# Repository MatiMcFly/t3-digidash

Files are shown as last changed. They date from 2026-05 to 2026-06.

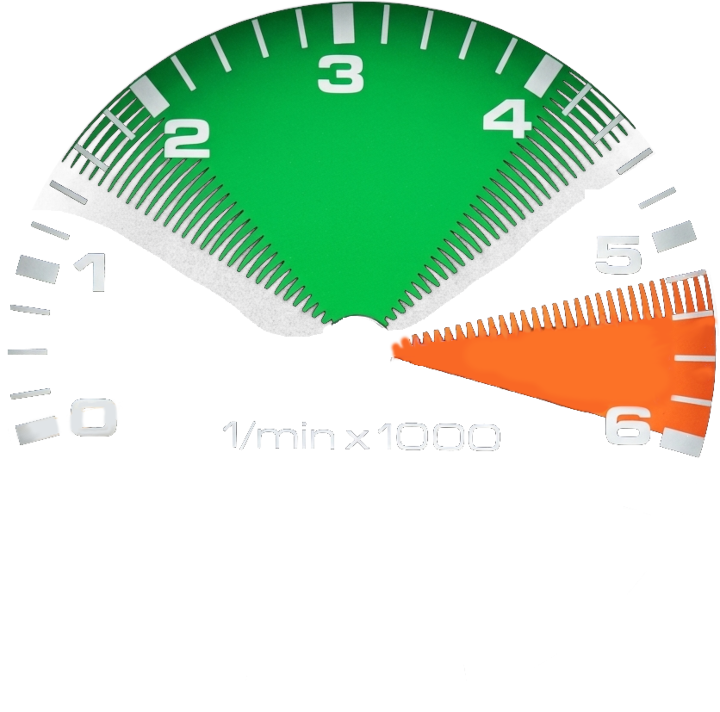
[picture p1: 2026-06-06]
fw/disco/CM7/TouchGFX/assets/images/t3-rpm-scale.png

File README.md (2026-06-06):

# 🛻 T3 DigiDash -- Digital dashboard for the VW T3

(C) 2026 Matthias Schär, Rinaldo Leone, Timon Burkard

This is a project work part of the CAS Embedded Systems at FHNW Brugg-Windisch.

## Docs

Documentation, specification etc. can be found in [docs](docs/) directory.

## FW

This project consists of three firmware projects:

- [Disco](fw/disco/) -- ST Discovery Kit: STM32H747I-DISCO
- [Nucleo](fw/nucleo/) -- ST Nucleo Board: NUCLEO-H755ZI-Q
- [ESP](fw/esp/) -- Seeed ESP Board: ESP-C3

## HW

This project consists of four hardware projects:

- [disco-tft-adapter](hw/disco-tft-adapter/) -- Discovery Board TFT Adapter
- [t3-harness-adapter](hw/t3-harness-adapter/) -- T3 Wiring harness adapter
- [measurement-circuits](hw/measurement-circuits/) -- Collects all of the measurement circuits used
- [signal-emulator](hw/signal-emulator/) -- Sensor signal emulator (used for testing and demonstration)

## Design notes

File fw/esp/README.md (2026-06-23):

# ESP32-C3 UART, BLE, and RemoteXY Bridge

This firmware receives ASCII telemetry over UART, parses it into car-signal values, and exposes those values over BLE.
It also embeds a RemoteXY-compatible BLE interface so a dashboard app can connect and read the same live data.

## What It Does
- Reads UART telemetry on GPIO4/GPIO5 at 115200 8N1
- Parses semicolon-separated `id:value` pairs into internal car-signal state
- Updates BLE characteristics for water temperature, RPM, battery voltage, tank level, turn signal, high beam, and oil-pressure switches
- Advertises a custom car-signals service plus standard Environmental Sensing and Battery services
- Exposes an HM-10-style BLE UART service for RemoteXY traffic
- Reconnects and re-advertises automatically after disconnects

## Current Firmware Layout
- `main/app_main.c` starts BLE, RemoteXY, and the UART task
- `main/uart_task.c` reads and parses UART telemetry
- `main/uart_parser.c` decodes the `id:value` message format
- `main/car_signals.c` stores signal state and triggers BLE notifications
- `main/gatt_db.c` defines the BLE GATT services and characteristics
- `main/remotexy_protocol.c` handles the RemoteXY command exchange

## Requirements
- ESP-IDF 6.0.1
- ESP32-C3 target
- A BLE client app such as nRF Connect, or a RemoteXY-compatible mobile app
- An external UART source that emits the expected telemetry format

## Build and Flash
```bash
idf.py set-target esp32c3
idf.py build
idf.py -p <PORT> flash monitor
```

## Hardware Wiring
- ESP32-C3 GPIO4 (UART TX) -> RX of the external device
- ESP32-C3 GPIO5 (UART RX) -> TX of the external device
- GND -> GND
- RTS/CTS are not used

## UART Message Format
The parser expects a semicolon-separated stream of `id:value` pairs.

Example:
```text
1:23.5;2:1500;3:12.6;4:18.2;5:1;6:0;7:1;8:0;
```

Field mapping:
- `1` = water temperature
- `2` = RPM
- `3` = battery voltage
- `4` = tank level
- `5` = turn signal
- `6` = high beam
- `7` = oil pressure switch 0.3B
- `8` = oil pressure switch 1.8B

The parser is tolerant of streaming input and collects bytes until it finds `;` separators.

## BLE Services
The firmware advertises as `T3 DigiDash`.

Available services:
- Standard Environmental Sensing service `0x181A`
	- Temperature characteristic `0x2A6E`
- Standard Battery service `0x180F`
	- Battery Level characteristic `0x2A19`
- HM-10 compatible UART service `0xFFE0`
	- UART characteristic `0xFFE1` for RemoteXY command traffic
- Custom Car Signals service `c4e7b1a2-0f3d-4f2a-8d89-0d92b48e7d21`
	- RPM
	- Turn Signal
	- High Beam
	- Tank Level
	- Battery Voltage

Use nRF Connect to inspect the GATT table and enable notifications on the characteristics you want to watch.

## RemoteXY
RemoteXY support is built in and uses the BLE UART characteristic for control packets.
The firmware responds to configuration, ping, time, board, and variable update commands so a compatible dashboard can connect without extra glue code.

## UART Simulator
A small Python-based UART generator is available in `uart_py_simulator/` for local testing.
See that folder's README for setup and run commands.

## Notes
- BLE notifications are chunked for the UART/RemoteXY path
- Hardware flow control is disabled
- The project currently focuses on live telemetry bridging rather than local UI or storage

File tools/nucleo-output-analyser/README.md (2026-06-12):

# Motor RPM Tools

Two Python scripts for capturing and visualising motor RPM data from a serial device.

## Requirements

```bash
pip install -r requirements.txt
```

---

## `live_motor_rpm.py` — Live serial monitor

Connects to a serial port, parses incoming datasets and displays a continuously
scrolling RPM plot in real time.

```
usage: live_motor_rpm.py [--port PORT] [--baud BAUD] [--window SECONDS]

options:
  --port    Serial device to read from   (default: /dev/ttyACM0)
  --baud    Baud rate                    (default: 115200)
  --window  Visible time window (s)      (default: 60)
```

**Examples**

```bash
# Use defaults (/dev/ttyACM0, 115200 baud, 60 s window)
python3 live_motor_rpm.py

# USB adapter at 9600 baud, show last 2 minutes
python3 live_motor_rpm.py --port /dev/ttyUSB0 --baud 9600 --window 120
```

---

## `plot_motor_rpm.py` — Log file plotter

Parses a minicom log file and plots the recorded RPM values over time.
Prints basic statistics (min, max, mean RPM) to the terminal.

```
usage: plot_motor_rpm.py [logfile] [--interval SECONDS]

arguments:
  logfile     Path to the minicom log file  (default: data/minicom-output.log)

options:
  --interval  Sample interval in seconds    (default: 0.1)
```

**Examples**

```bash
# Use the default log file (data/minicom-output.log)
python3 plot_motor_rpm.py

# Specify a different log file
python3 plot_motor_rpm.py data/my_run.log

# Log recorded at 20 Hz (0.05 s per sample)
python3 plot_motor_rpm.py data/my_run.log --interval 0.05
```

---

## Expected serial / log format

Both tools expect datasets delimited by a `Turn Signal:` line, with an optional
`Motor RPM:` line inside each dataset:

```
Turn Signal: ...
Motor RPM:   1450 rpm
...
Turn Signal: ...
Motor RPM:   1480 rpm
...
```

Datasets missing a `Motor RPM:` line are recorded as **0 RPM**.

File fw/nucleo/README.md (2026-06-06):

# Nucleo Firmware

Firmware for the STM32H755XI microcontroller with ARM Cortex-M7 and Cortex-M4 core, which is on a NUCLEO-H755ZI-Q board.

M4 core handles all sensor data related operations and then sends processed sensor data to M7 via IPC (Inter-processor communication), which handles UART communication.

## Features

- **M4 Core**
  - Sensor data acquisition (ADC + DMA)
  - Data conversion
  - Data filtering
  - Debug message publication via UART3 (virtual serial COM port)
  - IPC transmission to M7 via FreeRTOS message buffer in shared SRAM4 and notification via HSEM1
  - Heartbeat LED (LD1)
- **M7 Core**
  - IPC reception from shared message buffer, notification via HSEM1
  - UART1 output of received sensor messages
  - Heartbeat LED (LD2)

## Pinout

| Function | Core | Peripheral | Pins |
| --- | ---- | --- | --- |
| Sensor 1: Coolant temperature  | M4 | ADC1_INP2  | PF11 |
| Sensor 2: Motor RPM | M4 | TIM2_CH1 | PA0 |
| Sensor 3: Battery voltage | M4 | ADC1_INP3  | PA6 |
| Sensor 4: Fuel level | M4 | ADC1_INP5  | PB1 |
| Sensor 5: Turn signal | M4 | GPIO | D0 |
| Sensor 6: High beam | M4 | GPIO | D1 |
| Sensor 7: Oil pressure 0.3 bar | M4 | GPIO | D2 |
| Sensor 8: Oil pressure 1.8 bar | M4 | GPIO | D3 |
| Debug UART | M4 | USART3 | PD8 (TX), PD9 (RX) |
| Output UART | M7 | USART1 | PB14 (TX), PB15 (RX) |
| Heartbeat LED | M4 | GPIO | PB0 (LD1) |
| Heartbeat LED | M7 | GPIO | PE1 (LD2) |

## UART

- Baud: 115'200
- Data: 8 bit
- Stop: 1 bit
- Parity: None

### Output UART

Formatted sensor data frames:

```
<id>:<value>
```

### Debug UART

No strict format; debugging purpose only.

## Flow Chart

### M4 Core

```mermaid
flowchart TB
    ACQ[Acquisition Task\n1 Hz trigger]
    ISR[HAL_ADC_ConvCpltCallback]
    CONV[Conversion Task]
    FILT[Filtering Task]
    PUB[Publication Task]
    HB[Heartbeat Task]

    QRAW[(queue_data_raw)]
    QCONV[(queue_data_converted)]
    QFILT[(queue_data_filtered)]
    IPC[(MessageBuffer in SRAM4)]
    HSEM[(HSEM1 notify)]

    ADC[(ADC1 + DMA1 Stream0)]
    UART[(Debug USART3)]
    LED[(LD1)]

    ACQ -->|HAL_ADC_Start_DMA| ADC
    ADC -->|DMA transfer complete IRQ| ISR

    ISR -->|xQueueSendFromISR| QRAW

    QRAW -->|xQueueReceive| CONV
    CONV -->|xQueueSend| QCONV

    QCONV -->|xQueueReceive| FILT
    FILT -->|xQueueSend| QFILT

    QFILT -->|xQueueReceive| PUB
    PUB -->|HAL_UART_Transmit| UART
    PUB -->|xMessageBufferSend| IPC
    IPC -->|send completed callback| HSEM

    HB -->|toggle every 1 s| LED
```

### M7 Core

```mermaid
flowchart TB
  ISR[HAL_HSEM_FreeCallback]
  PUB[Publication Task]
    HB[Heartbeat Task]
  IPC[(MessageBuffer in SRAM4)]
  HSEM[(HSEM1 IRQ)]
  UART[(USART1)]
    LED[(LD2)]

  HSEM --> ISR
  ISR -->|xMessageBufferSendCompletedFromISR| PUB
  PUB -->|xMessageBufferReceive| IPC
  PUB -->|HAL_UART_Transmit| UART
    HB -->|toggle every 1 s| LED
```

## Build

### Requirements
- [STM32 for VS Code extension](https://marketplace.visualstudio.com/items?itemName=stmicroelectronics.stm32-vscode-extension)
- STM32CubeMX v6.17.0 (optional, for .ioc modifications)
- `git submodule init` and `git submodule update`

### Compilation

Open the workspace `fw/nucleo/` in VS Code.
- Click "Yes" on pop-up "Configure discovered Cmake projects(s) as STM32Cube project(s)?"
  - Assign projects to corresponding cores
- Ctrl-Shift-B: Use **CMake: clean rebuild** or **CMake: build**

### Unit Tests

The conversion module can be tested natively on the host without building the STM32 firmware target.

From `fw/nucleo/` run:

```powershell
cmake -S tests -B tests/build
cmake --build tests/build
ctest --test-dir tests/build --output-on-failure
```

### Debugging

- Start debugging session "DualCore_Debug"
- On CM4 click run button
- On CM7 click run button

LD1 is blinking while M4 is running. LD2 is blinking while M7 is running.

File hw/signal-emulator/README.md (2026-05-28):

## Signal Emulator

This KiCAD project contains a simple sensor signal emulator.

It will be used for testing and for the demonstration, as part of the project presentation.

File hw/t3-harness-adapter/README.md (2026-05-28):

## T3 Wiring harness adapter

This KiCAD project contains an adapter which can be used to retrieve the electrical signals from a VW T3 wiring harness.

The PCB has a board edge connector which adapts to the T3 dash wiring harness plug. All signals available are routed to pin headers for usage with other electronics, such as a STM32 development kit.

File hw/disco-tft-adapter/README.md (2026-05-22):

# 🖥️ Discovery Board TFT Adapter

This project contains the KiCad hardware design for a TFT display adapter designed to connect a TFT panel (GX040R-30MB-A1ICNL9707) to an STMicroelectronics STM32H747I Discovery Kit.

The adapter board includes circuitry to interface the display with the Discovery board, including a TPS61169 LED driver for the display backlight.

## 🔌 Connectivity between DISCO board and GX040R display

- according to the manufacturer, the display has to be connected as follows: Board (DP/N0) to LCD (DP/N1) and (DP/N1) to (DP/N3). A previous revision A of this board has gotten this wrong. D0 of the board has been connected to D0 of the TFT and D1 of the board to D1 of the TFT.
- CTP (capacitive touch display) functionalities (I2C, INT, ...) are not used

## 📚 Datasheets and Documentation

All relevant datasheets, manuals, and reference documents can be found in this [Google Drive folder](https://drive.google.com/drive/folders/1Etk3SSePW-oP0WRn9YrgEl5WCk2nYt2u?usp=sharing).

### 📋 Document Overview:

* **`disco_tft_adapter.pdf`** - The schematic for this adapter board project.
* **`GX040R-30MB-A1(V1).pdf`** - Datasheet for the TFT display panel used with this adapter.
* **`ICNL_9707_Datasheet...pdf`** - Datasheet for the ICNL9707, the display driver IC integrated into the TFT panel (might be obsolete)
* **`tps61169.pdf`** - Datasheet for the Texas Instruments TPS61169, the WLED driver IC used on this adapter for the display backlight.
* **`stm32h747-datasheet.pdf`** - Electrical characteristics and pinout for the STM32H747 microcontroller.
* **`stm32h747-ref-manual.pdf`** - Detailed reference manual for the STM32H747 MCU peripherals and registers.
* **`stm32h747-prog-manual.pdf`** - Programming manual detailing the architecture and instruction set for the STM32H747.
* **`mb1166-default-a09-schematic.pdf`** - Schematic for the MB1166 base board of the STM32H7 Discovery kit.
* **`mb1248-h747i-d03-schematic.pdf`** - Schematic for the MB1248 CPU board of the STM32H747I-DISCO kit.
* **`um2411-discovery-kit-...pdf`** - Official user manual (UM2411) for the STM32H747I-DISCO Discovery kit.
* **`JD9365DA-H3_User_Guide_Preliminary_V0.00_20200827.pdf` - User guide for the display driver. This is the last version that was received from the contact person at the display manufacturer.

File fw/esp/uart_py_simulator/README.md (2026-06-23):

UART Generator
==============

Small command-line utility that replays semicolon-delimited UART telemetry files over a serial port.
It is useful for driving the ESP32 firmware with repeatable input while developing or testing the BLE and RemoteXY side.

What it sends
-------------

- Reads messages from `UART-Data_Produced-By-Nucleo_With-Emulated-Sensor-Input.txt`
- Splits the file on `;` and sends each non-empty package in sequence
- Appends a trailing `;` to each transmitted package
- Repeats the file in a loop at the requested interval

Requirements
------------

- Python 3.14 or newer
- Poetry
- `pyserial`

Setup
-----

- Install dependencies:

	poetry install

- Activate the virtual environment on PowerShell if you want to run the script directly:

	.\.venv\Scripts\Activate.ps1

Run
---

- Default settings:

	poetry run uart-generator

- From the activated virtual environment:

	uart-generator

- Custom serial port, baud rate, and data file:

	poetry run uart-generator --port COM6 --baudrate 115200 --data-file UART-Data_Produced-By-Nucleo_With-Emulated-Sensor-Input_scaled.txt

- Custom interval, for example 20 Hz:

	poetry run uart-generator --interval 0.05

- Add a line ending if your receiver expects one:

	poetry run uart-generator --newline "\n"

Options
-------

- `--port`: Serial port, default `COM6`
- `--baudrate`: Serial baud rate, default `115200`
- `--data-file`: Path to the semicolon-delimited input file
- `--interval`: Seconds between packages, default `1 / 70`
- `--newline`: Extra line ending appended after the trailing `;`

Notes
-----

- The script prints the first few outgoing payloads to stdout for quick verification.
- There are currently no automated tests in this folder.

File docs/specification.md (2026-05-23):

# T3 Digidash - Spezifikation

**Projektarbeit CAS Embedded Systems 2026**

**Team:** Rinaldo Leone, Timon Burkard, Matthias Schär

**Dozenten:** Michael Pichler, Dominique Kunz, Manuel Di Cerbo

**Datum:** 23. Mai 2026

## Inhaltsverzeichnis

1. Projektbeschreibung
2. Verwendete Hardware
3. Anforderungen
4. Systemübersicht
5. Planung
6. Quellen

## 1. Projektbeschreibung

Zum Abschluss des CAS Embedded Systems soll ein verteiltes System entwickelt werden. Dieses wird in einem VW Transporter Typ 2.5 eingesetzt, um verschiedene analoge Instrumente im Armaturenbrett zu ersetzen. Einfache analoge Anzeigeelemente beschränken sich typischerweise auf den Tankfüllstand und die Kühlwassertemperatur. Der Kabelbaumabgriff, welcher zum Tacho führt, beinhaltet jedoch noch diverse andere nützliche Signale, wie zum Beispiel die Drehzahlanzeige. Mit Hilfe eines passenden TFT-LCD kann somit eine konfigurierbare und dynamische digitale Anzeige gestaltet werden. Diese bietet weiter die Möglichkeit, zusätzliche, nicht originale Anzeigeelemente anzuschliessen, wie zum Beispiel einen Sensor zur Messung der Öltemperatur.

Nachfolgend eine Auflistung aller Grössen, die im Rahmen dieses Projektes verwendet werden:

| Signal | Sensor-Typ | Messgrösse | Wertebereich | Bemerkungen |
| --- | --- | --- | --- | --- |
| Wassertemperatur | NTC gegen Chassis-GND | 1100 - 100 Ohm | -10 ... 150 °C | |
| Drehzahl | Pulse von Zündspule | 12V | 0 ... 7000 U/min | Achtung, Spannungsspitzen. Via Optokoppler messen. Skaliert mit Faktor 4 |
| Batteriespannung | Spannungsteiler | - | 0 ... 20 V | |
| Tankfüllstand | Hebelgeber gegen Chassis-GND | 40 ... 300 Ohm | 0 ... 80 l | |
| Blinker | Schalter | 12V / 0V | on / off | |
| Fernlicht | Schalter | 12V / 0V | on / off | |
| Öldruckschalter 0.3 bar | Schalter | 12V / 0V | on / off | |
| Öldruckschalter 1.8 bar | Schalter | 12V / 0V | on / off | |

## 2. Verwendete Hardware

Das System besteht aus drei eigenständigen Hardware-Plattformen, die über digitale Schnittstellen
miteinander kommunizieren, sowie aus mehreren projektspezifischen Adapterplatinen.

### 2.1 Mikrocontroller-Boards

- **ST Nucleo NUCLEO-H755ZI-Q** (STM32H755ZI, Dual-Core Cortex-M7 + Cortex-M4)
  Sensor-Frontend: Erfassung, Aufbereitung und Bereitstellung aller Fahrzeugsignale.
- **ST Discovery Kit STM32H747I-DISCO** (STM32H747XI, Dual-Core Cortex-M7 + Cortex-M4, 4.3" TFT)
  Anzeige-Einheit: Rendert das digitale Armaturenbrett auf dem integrierten TFT-LCD.
- **Seeed Studio XIAO ESP32-C3** (RISC-V, WiFi/BLE)
  Wireless-Bridge: Stellt die Messdaten via BLE (und optional WiFi) für externe Geräte
  (z.B. Smartphone) zur Verfügung.

### 2.2 Eigenentwickelte Hardware

- **`measurement-circuits`** -- Sammlung der Messschaltungen (Spannungsteiler, Optokoppler-
  Eingangsstufe für die Drehzahl, Pull-Up-Beschaltungen für NTC / Hebelgeber, Schutzbeschaltung
  gegen Transienten aus dem Bordnetz).
- **`t3-harness-adapter`** -- Adapter zwischen dem originalen VW T3 Kabelbaum-Stecker am
  Armaturenbrett und der Nucleo-Plattform inkl. der Messschaltungen.
- **`disco-tft-adapter`** -- Adapter zwischen dem Discovery Kit und den im Fahrzeug verbauten
  Bedienelementen / Versorgung.

### 2.3 Schnittstellen

- **Bordnetz:** 12 V (Klemme 15 / 30), Chassis-GND
- **Nucleo &harr; Disco:** UART (zukünftig optional CAN)
- **Nucleo &harr; ESP:** UART
- **ESP &harr; Host (Handy/PC):** BLE GATT
- **Disco &harr; TFT:** RGB / MIPI-DSI (boardseitig vorhanden)

## 3. Anforderungen

### 3.1 Muss-Anforderungen

- Ausmessen aller signale aus 1.
  - Wassertemperatur
  - Drehzahl
  - Batteriespannung
  - Tankfüllstand
  - Blinker
  - Fernlicht
  - Öldruckschalter 0.3 bar
  - Öldruckschalter 1.8 bar
- die Signale werden mit fixer Samplingrate ausgemessen (z.B. 10 Hz)
- die Signale werden geeignet gefiltert
- die Signale werden über UART vom Nucleo Board auf ein Discovery-Kit und ein ESP32 übertragen
- das ESP32-C3 publiziert die Messsignale über Bluetooth Low Energy (BLE)
- das Discovery-Kit stellt die Messsignale auf einem TFT LCD dar

### 3.2 Soll-Anforderungen

- die komplette Software soll portabel verfasst sein, für eine einfache Integration auf custom board
- die Auslastung der CPUs soll stetig überprüft werden
- die Anzeige auf dem TFT LCD soll an einen originalen T3 Tacho angeglichen sein
- das Projekt soll modular aufgebaut sein, erlaubt zukünftige Erweiterungen (weitere Sensoren / Instrumente)

### 3.3 Kann-Anforderungen

- die TFT LCD Anzeige ist konfigurierbar
- die TFT LCD Anzeige lässt sich kalibrieren
- Konfiguration und Kalibration können persistent gespeichert werden
- eine Android App stellt die über BLE empfangenen Werte auf einem Dashboard dar

## 4. Systemübersicht

Das System ist als verteiltes Embedded-System aufgebaut. Die Sensorerfassung, die
Visualisierung und die drahtlose Anbindung sind bewusst auf drei separate Plattformen verteilt,
um Verantwortlichkeiten klar zu trennen und unabhängige Entwicklung im Team zu ermöglichen.

System Overview

Die Nucleo-Plattform ist die zentrale Datenquelle. Sie liest alle Fahrzeugsignale ein,
normalisiert sie zu physikalischen Grössen und stellt sie zyklisch zur Verfügung. Discovery
Kit und ESP32-C3 sind reine Konsumenten dieser Daten und tauschen mit der Nucleo nur
strukturierte Telemetrie-Frames aus.

Der gesamte Code soll portabel gestaltet werden. In einem finalen Produkt wird das verteilte System
zusammengeführt auf einer einzelnen Hauptplatine. Dies wird jedoch nicht im Rahmen dieses Projektes umgesetzt.

### 4.1 Nucleo -- Sensor-Frontend

Nucleo

Auf der Nucleo läuft die komplette Signalverarbeitungs-Pipeline. Diese ist als FreeRTOS-Anwendung
auf dem Cortex-M7 (CM7) und Cortex-M4 (CM4) realisiert und in vier klar getrennte Stufen
aufgeteilt:

- **Acquisition** -- Erfassung der Rohwerte aus den Peripherien:
  ADC für Wassertemperatur, Tankfüllstand und Batteriespannung; Timer im Input-Capture-Modus
  für die Drehzahl-Pulse; GPIO mit Interrupt für die Schalter (Blinker, Fernlicht,
  Öldruck 0.3 / 1.8 bar).
- **Conversion** -- Umrechnung der Rohwerte in physikalische Grössen anhand der in
  [sensor-measurements.md](sensor-measurements.md) beschriebenen Kennlinien (Spannungsteiler,
  Beta-Gleichung für NTC, lineare Kennlinie für den Hebelgeber, Frequenz/4 für die Drehzahl).
- **Filtering** -- Glättung der zeitdiskreten Messwerte (z.B. gleitender Mittelwert,
  Hysterese für Schaltsignale, Plausibilitätsprüfung).
- **Publication** -- Serialisierung der gefilterten Werte zu einem Telemetrie-Frame und
  zyklische Ausgabe über die UART-Schnittstellen an Disco und ESP.

Die beiden Cores teilen sich die Arbeit:
- Der CM4 übernimmt die zeitkritische Acquisition, die Conversion und das Filtering.
- Der CM7 übernimmt lediglich die Publication via UART.
  - In Zukunft können die beiden STM32-Projekt dann einfach auf einer Platform kombiniert werden: CM4 von Nucleo wird auf CM4 von Disco migriert
  - Im Rahmen dieses Projektes wird das nicht gemacht. Es werden bewusst zwei STM32-Platformen verwendet, da alle Projekt-Mitglieder ein Nucleo-Board haben, aber nur ein Disco-Board zur Verfügung steht.

Die Inter-Core-Kommunikation erfolgt über den Shared-SRAM via FreeRTOS message buffer und Benachrichtigung via HSEM.

### 4.2 Discovery Kit -- Anzeige

Discovery Kit

Das Discovery Kit STM32H747I-DISCO ist über den `disco-tft-adapter` mit dem TFT-LCD
verbunden und stellt das digitale Armaturenbrett dar. Es empfängt zyklisch Telemetrie-Frames
von der Nucleo via UART, dekodiert diese und aktualisiert die Anzeige.

Die Render-Pipeline basiert auf TouchGFX / LTDC und nutzt den integrierten Framebuffer im SDRAM.
Sofern es die Rechenleistung zulässt ist der CM7 für die gesamte Funktionalität verantwortlich: Vom UART-Empfang, frame parsing hin zum Rendering des UIs

Folgende Anzeigen sind vorgesehen:

- Drehzahlmesser (analog dargestellt)
- Wassertemperatur (analog dargestellt)
- Tankfüllstand (analog dargestellt)
- Batteriespannung (digital)
- Statusicons für Blinker, Fernlicht, Öldruckwarnung

Folgende Flows müssen realisiert werden:

- UART receiver
- Frame parser
- UI Manager
- DSI TFT Driver

### 4.3 ESP32-C3 -- Wireless-Bridge

ESP32-C3

Der ESP32-C3 empfängt die gleichen Telemetrie-Frames wie das Discovery Kit über UART
und stellt sie via BLE GATT als Notify-Characteristic zur Verfügung. Ein Smartphone oder
ein Laptop kann sich verbinden und die Daten z.B. in einer Telemetrie-App live mitlesen
oder zu Diagnosezwecken aufzeichnen.

Auf dem ESP läuft FreeRTOS (ESP-IDF) mit zwei Tasks:

- **UART-RX-Task** -- empfängt Frames von der Nucleo, validiert und puffert sie.
- **BLE-Task** -- sendet die zuletzt empfangenen Daten als BLE-Notification an den
  verbundenen Client.

Optional kann der ESP zusätzlich einen WiFi-Stack starten, um die Daten via MQTT oder
HTTP an einen Telemetrie-Server zu pushen.

## 5. Planung

Siehe Anhang.

## 6. Quellen

- Volkswagen AG, *VW T3 Stromlaufplan*, Werkstatthandbuch
- Volkswagen AG, *Reparaturleitfaden VW Transporter -- Elektrische Anlage*, Werkstatthandbuch
- Dieter Korp, *Jetzt helfe ich mir selbst -- VW Transporter T3*, Motorbuch Verlag
- T3-Pedia, *VW1301 Widerstandskennwerte und -anwendung*,
  https://www.t3-pedia.de/index.php?title=VW1301-Widerstandskennwerte_und_-anwendung,
  aufgerufen am 23.05.2026
- STMicroelectronics, *RM0399 Reference manual STM32H745/755 and STM32H747/757 advanced
  Arm-based 32-bit MCUs*, https://www.st.com/resource/en/reference_manual/rm0399-stm32h745755-and-stm32h747757-advanced-armbased-32bit-mcus-stmicroelectronics.pdf
- STMicroelectronics, *UM2411 Discovery kit with STM32H747XI MCU*,
  https://www.st.com/resource/en/user_manual/um2411-discovery-kit-with-stm32h747xi-mcu-stmicroelectronics.pdf
- STMicroelectronics, *UM2407 STM32H7 Nucleo-144 boards (MB1363)*,
  https://www.st.com/resource/en/user_manual/um2407-stm32h7-nucleo144-boards-mb1363-stmicroelectronics.pdf
- Espressif Systems, *ESP32-C3 Technical Reference Manual*,
  https://www.espressif.com/sites/default/files/documentation/esp32-c3_technical_reference_manual_en.pdf
- FreeRTOS, *FreeRTOS Kernel V11.3.0 Documentation*, https://www.freertos.org/

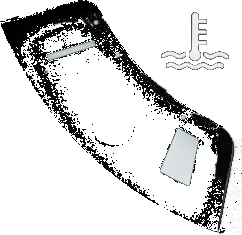
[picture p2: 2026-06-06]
fw/disco/CM7/TouchGFX/assets/images/t3-temperature-scale.png

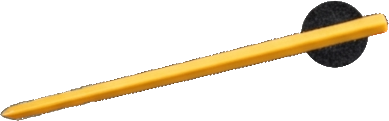
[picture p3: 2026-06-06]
fw/disco/CM7/TouchGFX/assets/images/t3-rpm-gauge.png

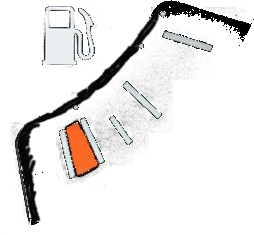
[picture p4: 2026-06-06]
fw/disco/CM7/TouchGFX/assets/images/t3-fuel-scale.png

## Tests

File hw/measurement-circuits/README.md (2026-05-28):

## Measurement Circuits

The T3 harness cannot be connect directly to the MCU. Some simple signal adjustments are needed, which are implemented in this KiCad project.

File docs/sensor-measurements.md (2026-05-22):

# Mathematical Evaluation of VW T3 Dashboard Sensors
This documentation describes the mathematical principles and formulas for evaluating analog sensors in the VW T3 using a microcontroller with a $3.3\,\text{V}$ signal level (e.g., ESP32 or STM32 with a 12-bit ADC).

## 1. Common Base: Resistance Measurement via Pull-Up

Since the sensors for fuel level and coolant temperature represent temperature- or level-dependent resistances against vehicle ground, they are operated via a known pull-up resistor $R_{\text{pullup}}$ connected to the stable $3.3\,\text{V}$ rail of the microcontroller.

### Voltage Divider Formula

The analog signal at the ADC pin is calculated as follows:

$$V_{\text{ADC}} = V_{\text{REF}} \cdot \frac{R_{\text{sense}}}{R_{\text{pullup}} + R_{\text{sense}}}$$

Conversely, the current sensor resistance $R_{\text{sense}}$ is calculated in the microcontroller from the measured voltage $V_{\text{ADC}}$:

$$R_{\text{sense}} = \frac{V_{\text{ADC}} \cdot R_{\text{pullup}}}{V_{\text{REF}} - V_{\text{ADC}}}$$

- $V_{\text{REF}} = 3.3\,\text{V}$ (Reference voltage of the microcontroller)
- $R_{\text{pullup}}$: Selected fixed resistor on the adapter board

## 2. Fuel Level

The original T3 lever-type sensor works mechanically linearly but has an inverted characteristic curve (high resistance when the tank is empty).

### Sensor Parameters

- Full (approx. 70 liters): $R_{\text{sense}} \approx 40\,\Omega$
- Empty (0 liters): $R_{\text{sense}} \approx 300\,\Omega$

### Calibrated Linear Equation (Liters as a function of $R_{\text{sense}}$)

$$L_{\text{tank}} = -0.269 \cdot R_{\text{sense}} + 80.8$$

### Complete Characteristic Curve Equation (Directly from $V_{\text{ADC}}$)

Substituting the resistance formula of the voltage divider yields the hyperbolically curved voltage equation:

$$L_{\text{tank}} = -0.269 \cdot \left( \frac{V_{\text{ADC}} \cdot R_{\text{pullup}}}{3.3 - V_{\text{ADC}}} \right) + 80.8$$

(Recommended Pull-Up: $R_{\text{pullup}} = 330\,\Omega$)

## 3. Coolant Temperature (NTC Sensor)

Negative Temperature Coefficient (NTC) thermistors exhibit a non-linear, exponential temperature behavior. The simplified Steinhart-Hart equation (Beta equation) is used for software evaluation.

### Sensor Parameters (calculated from VW specifications)

- Nominal Temperature ($T_0$): $20^\circ\text{C}$ ($293.15\,\text{K}$) $\rightarrow R_0 = 1100\,\Omega$
- Operating Temperature ($T_1$): $90^\circ\text{C}$ ($363.15\,\text{K}$) $\rightarrow R_1 = 105\,\Omega$
- Material Constant ($\beta$): $3572\,\text{K}$

### Beta Equation for Temperature Calculation

From the sensor resistance $R_{\text{sense}}$ determined via the voltage divider, the absolute temperature in Kelvin is calculated:

$$T_{\text{Kelvin}} = \frac{1}{\frac{1}{T_0} + \frac{1}{\beta} \cdot \ln\left(\frac{R_{\text{sense}}}{R_0}\right)}$$Consequently, the output in degrees Celsius is:$$T_{\text{Celsius}} = T_{\text{Kelvin}} - 273.15$$

(Recommended Pull-Up: $R_{\text{pullup}} = 470\,\Omega$)

## 4. Battery Voltage

The measurement of the board voltage is carried out via a classic voltage divider to step down the fluctuating automotive voltage to the level of the microcontroller.

### Circuit Design

- $R_1$: Resistor from Terminal 15/30 to the ADC pin (e.g., $10\,\text{k}\Omega$)
- $R_2$: Resistor from the ADC pin to ground (e.g., $2.2\,\text{k}\Omega$)

$$V_{\text{ADC}} = V_{\text{Batt}} \cdot \frac{R_2}{R_1 + R_2}$$

## Calculating the Real Battery Voltage in Code

From the voltage $V_{\text{ADC}}$ measured at the ADC, the board voltage $V_{\text{Batt}}$ is obtained:

$$V_{\text{Batt}} = V_{\text{ADC}} \cdot \frac{R_1 + R_2}{R_2}$$

With the example values ($R_1 = 10\,\text{k}\Omega$, $R_2 = 2.2\,\text{k}\Omega$), the factor simplifies to:

$$V_{\text{Batt}} = V_{\text{ADC}} \cdot \frac{12.2}{2.2} \approx V_{\text{ADC}} \cdot 5.545$$

⚠️ Protection Note: A $3.3\,\text{V}$ Zener diode should absolutely be connected in parallel with $R_2$ in order to reliably clip overvoltage transients from the vehicle electrical system.

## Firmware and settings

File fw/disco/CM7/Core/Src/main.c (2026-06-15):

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
/* Includes ------------------------------------------------------------------*/
#include "main.h"
#include "app_touchgfx.h"

/* USER CODE BEGIN Includes */
#include "App.h"

#include "FreeRTOS.h"
#include "task.h"

#include "QspiFlash.h"

/* USER CODE END Includes */

/* USER CODE BEGIN PD */

/* DUAL_CORE_BOOT_SYNC_SEQUENCE: Define for dual core boot synchronization    */
/*                             demonstration code based on hardware semaphore */
/* This define is present in both CM7/CM4 projects                            */
/* To comment when developping/debugging on a single core                     */
#define DUAL_CORE_BOOT_SYNC_SEQUENCE

#if defined(DUAL_CORE_BOOT_SYNC_SEQUENCE)
#ifndef HSEM_ID_0
#define HSEM_ID_0 (0U) /* HW semaphore 0*/
#endif
#endif /* DUAL_CORE_BOOT_SYNC_SEQUENCE */

/* USER CODE END PD */


CRC_HandleTypeDef hcrc;

DMA2D_HandleTypeDef hdma2d;

DSI_HandleTypeDef hdsi;

LTDC_HandleTypeDef hltdc;

QSPI_HandleTypeDef hqspi;

TIM_HandleTypeDef htim17;

UART_HandleTypeDef huart1;
UART_HandleTypeDef huart2;

SDRAM_HandleTypeDef hsdram1;

/* USER CODE BEGIN PV */

/* MDMA channel used by TouchGFX partial-framebuffer strategy to push a
 * fully-rendered block from AXI-SRAM into the LTDC framebuffer in SDRAM
 * without occupying DMA2D (which is reserved for the rendering queue
 * inside STM32DMA.cpp). MDMA has its own AXI master path so it does not
 * fight DMA2D for AHB bandwidth. */
MDMA_HandleTypeDef hmdma_display;

/* USER CODE END PV */

void SystemClock_Config(void);
void PeriphCommonClock_Config(void);
static void MPU_Config(void);
static void MX_GPIO_Init(void);
static void MX_USART1_UART_Init(void);
static void MX_DSIHOST_DSI_Init(void);
static void MX_LTDC_Init(void);
static void MX_FMC_Init(void);
static void MX_TIM17_Init(void);
static void MX_CRC_Init(void);
static void MX_DMA2D_Init(void);
static void MX_QUADSPI_Init(void);
static void MX_USART2_UART_Init(void);
/* USER CODE BEGIN 0 */

#define SDRAM_MODEREG_BURST_LENGTH_1             0x0000U
#define SDRAM_MODEREG_BURST_TYPE_SEQUENTIAL      0x0000U
#define SDRAM_MODEREG_CAS_LATENCY_2              0x0020U
#define SDRAM_MODEREG_CAS_LATENCY_3              0x0030U
#define SDRAM_MODEREG_OPERATING_MODE_STANDARD    0x0000U
#define SDRAM_MODEREG_WRITEBURST_MODE_SINGLE     0x0200U

static void SDRAM_Initialization_Sequence(SDRAM_HandleTypeDef *hsdram)
{
  FMC_SDRAM_CommandTypeDef command = {0};
  uint32_t mode = 0U;

  command.CommandTarget = FMC_SDRAM_CMD_TARGET_BANK2;
  command.AutoRefreshNumber = 1U;
  command.ModeRegisterDefinition = 0U;

  command.CommandMode = FMC_SDRAM_CMD_CLK_ENABLE;
  if (HAL_SDRAM_SendCommand(hsdram, &command, HAL_MAX_DELAY) != HAL_OK)
  {
    Error_Handler();
  }

  HAL_Delay(1);

  command.CommandMode = FMC_SDRAM_CMD_PALL;
  if (HAL_SDRAM_SendCommand(hsdram, &command, HAL_MAX_DELAY) != HAL_OK)
  {
    Error_Handler();
  }

  command.CommandMode = FMC_SDRAM_CMD_AUTOREFRESH_MODE;
  command.AutoRefreshNumber = 8U;
  if (HAL_SDRAM_SendCommand(hsdram, &command, HAL_MAX_DELAY) != HAL_OK)
  {
    Error_Handler();
  }

  mode = SDRAM_MODEREG_BURST_LENGTH_1 |
         SDRAM_MODEREG_BURST_TYPE_SEQUENTIAL |
         SDRAM_MODEREG_CAS_LATENCY_3 |
         SDRAM_MODEREG_OPERATING_MODE_STANDARD |
         SDRAM_MODEREG_WRITEBURST_MODE_SINGLE;

  command.CommandMode = FMC_SDRAM_CMD_LOAD_MODE;
  command.AutoRefreshNumber = 1U;
  command.ModeRegisterDefinition = mode;
  if (HAL_SDRAM_SendCommand(hsdram, &command, HAL_MAX_DELAY) != HAL_OK)
  {
    Error_Handler();
  }

  /* 100MHz SDRAM clock: (64ms / 8192) * 100MHz - margin(20) = 761 */
  if (HAL_SDRAM_ProgramRefreshRate(hsdram, 761U) != HAL_OK)
  {
    Error_Handler();
  }
}

static void ConfigureMpuForSdram(void)
{
  MPU_Region_InitTypeDef region = {0};

  HAL_MPU_Disable();

  /* Framebuffer in SDRAM Bank2 @ 0xD0000000, keep non-cacheable for LTDC coherency. */
  region.Enable = MPU_REGION_ENABLE;
  region.Number = MPU_REGION_NUMBER1;
  region.BaseAddress = 0xD0000000U;
  region.Size = MPU_REGION_SIZE_16MB;
  region.SubRegionDisable = 0x00U;
  region.TypeExtField = MPU_TEX_LEVEL0;
  region.AccessPermission = MPU_REGION_FULL_ACCESS;
  region.DisableExec = MPU_INSTRUCTION_ACCESS_DISABLE;
  region.IsShareable = MPU_ACCESS_SHAREABLE;
  region.IsCacheable = MPU_ACCESS_NOT_CACHEABLE;
  region.IsBufferable = MPU_ACCESS_BUFFERABLE;

  HAL_MPU_ConfigRegion(&region);

  /* External QSPI NOR @ 0x90000000, 128 MB (dual-flash, two MT25TL01G
   * dies in parallel = 2 x 64 MB).
   * Cacheable read-only so the M7 D-cache and prefetcher can speed up
   * asset reads and speculative writes are prevented. */
  region.Enable = MPU_REGION_ENABLE;
  region.Number = MPU_REGION_NUMBER2;
  region.BaseAddress = 0x90000000U;
  region.Size = MPU_REGION_SIZE_128MB;
  region.SubRegionDisable = 0x00U;
  region.TypeExtField = MPU_TEX_LEVEL0;
  region.AccessPermission = MPU_REGION_PRIV_RO_URO;
  region.DisableExec = MPU_INSTRUCTION_ACCESS_DISABLE;
  region.IsShareable = MPU_ACCESS_NOT_SHAREABLE;
  region.IsCacheable = MPU_ACCESS_CACHEABLE;
  region.IsBufferable = MPU_ACCESS_BUFFERABLE;

  HAL_MPU_ConfigRegion(&region);
  HAL_MPU_Enable(MPU_PRIVILEGED_DEFAULT);
}

/* MDMA setup for the TouchGFX partial-framebuffer block-transmit path.
 * Source = block buffer in AXI-SRAM (cacheable WB; framework calls
 * FlushCache before this is invoked). Destination = LTDC framebuffer in
 * SDRAM (non-cacheable per ConfigureMpuForSdram). MDMA copies a
 * rectangular region using its 2D-stride support: BlockDataLength = one
 * row of the dirty rect, BlockCount = number of rows. The destination
 * block-address-offset register is patched per-transfer so that the
 * destination pointer jumps a full LTDC stride after each row. */
static void MX_MDMA_Init(void)
{
  __HAL_RCC_MDMA_CLK_ENABLE();

  hmdma_display.Instance = MDMA_Channel0;
  hmdma_display.Init.Request = MDMA_REQUEST_SW;
  hmdma_display.Init.TransferTriggerMode = MDMA_REPEAT_BLOCK_TRANSFER;
  hmdma_display.Init.Priority = MDMA_PRIORITY_HIGH;
  hmdma_display.Init.Endianness = MDMA_LITTLE_ENDIANNESS_PRESERVE;
  hmdma_display.Init.SourceInc = MDMA_SRC_INC_BYTE;
  hmdma_display.Init.DestinationInc = MDMA_DEST_INC_BYTE;
  hmdma_display.Init.SourceDataSize = MDMA_SRC_DATASIZE_BYTE;
  hmdma_display.Init.DestDataSize = MDMA_DEST_DATASIZE_BYTE;
  hmdma_display.Init.DataAlignment = MDMA_DATAALIGN_PACKENABLE;
  hmdma_display.Init.BufferTransferLength = 128;
  hmdma_display.Init.SourceBurst = MDMA_SOURCE_BURST_16BEATS;
  hmdma_display.Init.DestBurst = MDMA_DEST_BURST_16BEATS;
  hmdma_display.Init.SourceBlockAddressOffset = 0;
  hmdma_display.Init.DestBlockAddressOffset = 0;

  if (HAL_MDMA_Init(&hmdma_display) != HAL_OK) {
    Error_Handler();
  }

  /* Priority NVIC: must be numerically >= configMAX_SYSCALL_INTERRUPT_PRIORITY
   * (5) because the TC callback signals the TouchGFX engine via the
   * generated startNewTransfer() path which may hit FreeRTOS APIs. */
  HAL_NVIC_SetPriority(MDMA_IRQn, 5, 0);
  HAL_NVIC_EnableIRQ(MDMA_IRQn);
}

/* USER CODE END 0 */

/**
  * @brief  The application entry point.
  * @retval int
  */
int main(void)
{

/* USER CODE BEGIN Boot_Mode_Sequence_0 */
#if defined(DUAL_CORE_BOOT_SYNC_SEQUENCE)
  int32_t timeout;
#endif /* DUAL_CORE_BOOT_SYNC_SEQUENCE */
/* USER CODE END Boot_Mode_Sequence_0 */

  /* MPU Configuration--------------------------------------------------------*/
  MPU_Config();

/* USER CODE BEGIN Boot_Mode_Sequence_1 */
#if defined(DUAL_CORE_BOOT_SYNC_SEQUENCE)
  /* Wait until CPU2 boots and enters in stop mode or timeout*/
  timeout = 0xFFFF;
  while((__HAL_RCC_GET_FLAG(RCC_FLAG_D2CKRDY) != RESET) && (timeout-- > 0));
  if ( timeout < 0 )
  {
  Error_Handler();
  }
#endif /* DUAL_CORE_BOOT_SYNC_SEQUENCE */
/* USER CODE END Boot_Mode_Sequence_1 */
  /* MCU Configuration--------------------------------------------------------*/

  /* Reset of all peripherals, Initializes the Flash interface and the Systick. */
  HAL_Init();

  /* USER CODE BEGIN Init */

  /* Enable Cortex-M7 instruction and data caches. */
  SCB_EnableICache();
  SCB_EnableDCache();

  /* USER CODE END Init */

  /* Configure the system clock */
  SystemClock_Config();

  /* Configure the peripherals common clocks */
  PeriphCommonClock_Config();
/* USER CODE BEGIN Boot_Mode_Sequence_2 */
#if defined(DUAL_CORE_BOOT_SYNC_SEQUENCE)
/* When system initialization is finished, Cortex-M7 will release Cortex-M4 by means of
HSEM notification */
/*HW semaphore Clock enable*/
__HAL_RCC_HSEM_CLK_ENABLE();
/*Take HSEM */
HAL_HSEM_FastTake(HSEM_ID_0);
/*Release HSEM in order to notify the CPU2(CM4)*/
HAL_HSEM_Release(HSEM_ID_0,0);
/* wait until CPU2 wakes up from stop mode */
timeout = 0xFFFF;
while((__HAL_RCC_GET_FLAG(RCC_FLAG_D2CKRDY) == RESET) && (timeout-- > 0));
if ( timeout < 0 )
{
Error_Handler();
}
#endif /* DUAL_CORE_BOOT_SYNC_SEQUENCE */
/* USER CODE END Boot_Mode_Sequence_2 */

  /* Initialize all configured peripherals */
  MX_GPIO_Init();
  MX_USART1_UART_Init();
  MX_DSIHOST_DSI_Init();
  MX_LTDC_Init();
  MX_FMC_Init();
  MX_TIM17_Init();
  MX_CRC_Init();
  MX_DMA2D_Init();
  MX_QUADSPI_Init();
  MX_USART2_UART_Init();
  MX_TouchGFX_Init();
  /* USER CODE BEGIN 2 */

  ConfigureMpuForSdram();

  MX_MDMA_Init();

  /* External QSPI NOR (2x MT25TL01G) -> map at 0x90000000 so TouchGFX
   * can fetch images/fonts placed in ExtFlashSection / FontFlashSection.
   * Requires MX_QUADSPI_Init() to have run first (added by CubeMX once
   * QUADSPI is enabled in the .ioc). */
  extern QSPI_HandleTypeDef hqspi;
  if (QspiFlash_InitMemoryMapped(&hqspi) != HAL_OK) {
      Error_Handler();
  }

  AppInit();

  /* USER CODE END 2 */

  /* Infinite loop */
  /* USER CODE BEGIN WHILE */
  vTaskStartScheduler();
  /* Should never reach here. */
  for (;;) {}
    /* USER CODE END WHILE */

  MX_TouchGFX_Process();
}

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
 /* MPU Configuration */

void MPU_Config(void)
{
  MPU_Region_InitTypeDef MPU_InitStruct = {0};

  /* Disables the MPU */
  HAL_MPU_Disable();

  /** Initializes and configures the Region and the memory to be protected
  */
  MPU_InitStruct.Enable = MPU_REGION_ENABLE;
  MPU_InitStruct.Number = MPU_REGION_NUMBER0;
  MPU_InitStruct.BaseAddress = 0x0;
  MPU_InitStruct.Size = MPU_REGION_SIZE_4GB;
  MPU_InitStruct.SubRegionDisable = 0x87;
  MPU_InitStruct.TypeExtField = MPU_TEX_LEVEL0;
  MPU_InitStruct.AccessPermission = MPU_REGION_NO_ACCESS;
  MPU_InitStruct.DisableExec = MPU_INSTRUCTION_ACCESS_DISABLE;
  MPU_InitStruct.IsShareable = MPU_ACCESS_SHAREABLE;
  MPU_InitStruct.IsCacheable = MPU_ACCESS_NOT_CACHEABLE;
  MPU_InitStruct.IsBufferable = MPU_ACCESS_NOT_BUFFERABLE;

  HAL_MPU_ConfigRegion(&MPU_InitStruct);
  /* Enables the MPU */
  HAL_MPU_Enable(MPU_PRIVILEGED_DEFAULT);

}

/**
  * @brief  This function is executed in case of error occurrence.
  * @retval None
  */
void Error_Handler(void)
{
  /* USER CODE BEGIN Error_Handler_Debug */
  /* User can add his own implementation to report the HAL error return state */
  __disable_irq();
  while (1)
  {
  }
  /* USER CODE END Error_Handler_Debug */
}
#ifdef USE_FULL_ASSERT
/**
  * @brief  Reports the name of the source file and the source line number
  *         where the assert_param error has occurred.
  * @param  file: pointer to the source file name
  * @param  line: assert_param error line source number
  * @retval None
  */
void assert_failed(uint8_t *file, uint32_t line)
{
  /* USER CODE BEGIN 6 */
  /* User can add his own implementation to report the file name and line number,
     ex: printf("Wrong parameters value: file %s on line %d\r\n", file, line) */
  /* USER CODE END 6 */
}
#endif /* USE_FULL_ASSERT */

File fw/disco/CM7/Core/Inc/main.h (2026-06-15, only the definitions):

#define FMC_D28_Pin GPIO_PIN_6
#define FMC_D28_GPIO_Port GPIOI
#define FMC_NBL3_Pin GPIO_PIN_5
#define FMC_NBL3_GPIO_Port GPIOI
#define FMC_NBL2_Pin GPIO_PIN_4
#define FMC_NBL2_GPIO_Port GPIOI
#define QSPI_BK2_IO2_Pin GPIO_PIN_9
#define QSPI_BK2_IO2_GPIO_Port GPIOG
#define FMC_D25_Pin GPIO_PIN_1
#define FMC_D25_GPIO_Port GPIOI
#define FMC_D24_Pin GPIO_PIN_0
#define FMC_D24_GPIO_Port GPIOI
#define FMC_D29_Pin GPIO_PIN_7
#define FMC_D29_GPIO_Port GPIOI
#define FMC_NBL1_Pin GPIO_PIN_1
#define FMC_NBL1_GPIO_Port GPIOE
#define FMC_D26_Pin GPIO_PIN_2
#define FMC_D26_GPIO_Port GPIOI
#define FMC_D23_Pin GPIO_PIN_15
#define FMC_D23_GPIO_Port GPIOH
#define FMC_D22_Pin GPIO_PIN_14
#define FMC_D22_GPIO_Port GPIOH
#define OSC32_OUT_Pin GPIO_PIN_15
#define OSC32_OUT_GPIO_Port GPIOC
#define OSC32_IN_Pin GPIO_PIN_14
#define OSC32_IN_GPIO_Port GPIOC
#define FMC_NBL0_Pin GPIO_PIN_0
#define FMC_NBL0_GPIO_Port GPIOE
#define FMC_D27_Pin GPIO_PIN_3
#define FMC_D27_GPIO_Port GPIOI
#define FMC_SDCAS_Pin GPIO_PIN_15
#define FMC_SDCAS_GPIO_Port GPIOG
#define QSPI_BK2_IO3_Pin GPIO_PIN_14
#define QSPI_BK2_IO3_GPIO_Port GPIOG
#define BL_CTRL_Pin GPIO_PIN_12
#define BL_CTRL_GPIO_Port GPIOJ
#define FMC_D2_Pin GPIO_PIN_0
#define FMC_D2_GPIO_Port GPIOD
#define STLINK_TX_Pin GPIO_PIN_10
#define STLINK_TX_GPIO_Port GPIOA
#define STLINK_RX_Pin GPIO_PIN_9
#define STLINK_RX_GPIO_Port GPIOA
#define FMC_D21_Pin GPIO_PIN_13
#define FMC_D21_GPIO_Port GPIOH
#define FMC_D30_Pin GPIO_PIN_9
#define FMC_D30_GPIO_Port GPIOI
#define FMC_D3_Pin GPIO_PIN_1
#define FMC_D3_GPIO_Port GPIOD
#define CEC_CK_MCO1_Pin GPIO_PIN_8
#define CEC_CK_MCO1_GPIO_Port GPIOA
#define FMC_D31_Pin GPIO_PIN_10
#define FMC_D31_GPIO_Port GPIOI
#define FMC_SDCLK_Pin GPIO_PIN_8
#define FMC_SDCLK_GPIO_Port GPIOG
#define FMC_A2_Pin GPIO_PIN_2
#define FMC_A2_GPIO_Port GPIOF
#define FMC_A1_Pin GPIO_PIN_1
#define FMC_A1_GPIO_Port GPIOF
#define FMC_A0_Pin GPIO_PIN_0
#define FMC_A0_GPIO_Port GPIOF
#define QSPI_BK1_NCS_Pin GPIO_PIN_6
#define QSPI_BK1_NCS_GPIO_Port GPIOG
#define FMC_A3_Pin GPIO_PIN_3
#define FMC_A3_GPIO_Port GPIOF
#define FMC_BA0_Pin GPIO_PIN_4
#define FMC_BA0_GPIO_Port GPIOG
#define DSI_Reset_Pin GPIO_PIN_3
#define DSI_Reset_GPIO_Port GPIOG
#define FMC_A12_Pin GPIO_PIN_2
#define FMC_A12_GPIO_Port GPIOG
#define JOY_SEL_Pin GPIO_PIN_2
#define JOY_SEL_GPIO_Port GPIOK
#define OSC_OUT_Pin GPIO_PIN_1
#define OSC_OUT_GPIO_Port GPIOH
#define OSC_IN_Pin GPIO_PIN_0
#define OSC_IN_GPIO_Port GPIOH
#define FMC_A5_Pin GPIO_PIN_5
#define FMC_A5_GPIO_Port GPIOF
#define FMC_A4_Pin GPIO_PIN_4
#define FMC_A4_GPIO_Port GPIOF
#define QSPI_BK1_IO3_Pin GPIO_PIN_6
#define QSPI_BK1_IO3_GPIO_Port GPIOF
#define QSPI_BK1_IO2_Pin GPIO_PIN_7
#define QSPI_BK1_IO2_GPIO_Port GPIOF
#define QSPI_BK1_IO1_Pin GPIO_PIN_9
#define QSPI_BK1_IO1_GPIO_Port GPIOF
#define QSPI_BK2_IO0_Pin GPIO_PIN_2
#define QSPI_BK2_IO0_GPIO_Port GPIOH
#define FMC_D7_Pin GPIO_PIN_10
#define FMC_D7_GPIO_Port GPIOE
#define QSPI_BK2_IO1_Pin GPIO_PIN_3
#define QSPI_BK2_IO1_GPIO_Port GPIOH
#define FMC_SDNWE_Pin GPIO_PIN_5
#define FMC_SDNWE_GPIO_Port GPIOH
#define FMC_A7_Pin GPIO_PIN_13
#define FMC_A7_GPIO_Port GPIOF
#define FMC_A8_Pin GPIO_PIN_14
#define FMC_A8_GPIO_Port GPIOF
#define FMC_D6_Pin GPIO_PIN_9
#define FMC_D6_GPIO_Port GPIOE
#define FMC_D8_Pin GPIO_PIN_11
#define FMC_D8_GPIO_Port GPIOE
#define FMC_D18_Pin GPIO_PIN_10
#define FMC_D18_GPIO_Port GPIOH
#define FMC_D19_Pin GPIO_PIN_11
#define FMC_D19_GPIO_Port GPIOH
#define FMC_D1_Pin GPIO_PIN_15
#define FMC_D1_GPIO_Port GPIOD
#define FMC_D0_Pin GPIO_PIN_14
#define FMC_D0_GPIO_Port GPIOD
#define QSPI_CLK_Pin GPIO_PIN_2
#define QSPI_CLK_GPIO_Port GPIOB
#define FMC_A6_Pin GPIO_PIN_12
#define FMC_A6_GPIO_Port GPIOF
#define FMC_A9_Pin GPIO_PIN_15
#define FMC_A9_GPIO_Port GPIOF
#define FMC_D9_Pin GPIO_PIN_12
#define FMC_D9_GPIO_Port GPIOE
#define FMC_D12_Pin GPIO_PIN_15
#define FMC_D12_GPIO_Port GPIOE
#define FMC_D17_Pin GPIO_PIN_9
#define FMC_D17_GPIO_Port GPIOH
#define FMC_D20_Pin GPIO_PIN_12
#define FMC_D20_GPIO_Port GPIOH
#define QSPI_BK1_IO0_Pin GPIO_PIN_11
#define QSPI_BK1_IO0_GPIO_Port GPIOD
#define FMC_SDRAS_Pin GPIO_PIN_11
#define FMC_SDRAS_GPIO_Port GPIOF
#define FMC_A10_Pin GPIO_PIN_0
#define FMC_A10_GPIO_Port GPIOG
#define FMC_D5_Pin GPIO_PIN_8
#define FMC_D5_GPIO_Port GPIOE
#define FMC_D10_Pin GPIO_PIN_13
#define FMC_D10_GPIO_Port GPIOE
#define FMC_SDNE1_Pin GPIO_PIN_6
#define FMC_SDNE1_GPIO_Port GPIOH
#define FMC_D16_Pin GPIO_PIN_8
#define FMC_D16_GPIO_Port GPIOH
#define FMC_D15_Pin GPIO_PIN_10
#define FMC_D15_GPIO_Port GPIOD
#define FMC_D14_Pin GPIO_PIN_9
#define FMC_D14_GPIO_Port GPIOD
#define FMC_A11_Pin GPIO_PIN_1
#define FMC_A11_GPIO_Port GPIOG
#define FMC_D4_Pin GPIO_PIN_7
#define FMC_D4_GPIO_Port GPIOE
#define FMC_D11_Pin GPIO_PIN_14
#define FMC_D11_GPIO_Port GPIOE
#define FMC_SDCKE1_Pin GPIO_PIN_7
#define FMC_SDCKE1_GPIO_Port GPIOH
#define FMC_D13_Pin GPIO_PIN_8
#define FMC_D13_GPIO_Port GPIOD

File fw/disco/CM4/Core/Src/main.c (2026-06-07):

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
/* Includes ------------------------------------------------------------------*/
#include "main.h"
#include "string.h"

/* USER CODE BEGIN PD */

/* DUAL_CORE_BOOT_SYNC_SEQUENCE: Define for dual core boot synchronization    */
/*                             demonstration code based on hardware semaphore */
/* This define is present in both CM7/CM4 projects                            */
/* To comment when developping/debugging on a single core                     */
#define DUAL_CORE_BOOT_SYNC_SEQUENCE

#if defined(DUAL_CORE_BOOT_SYNC_SEQUENCE)
#ifndef HSEM_ID_0
#define HSEM_ID_0 (0U) /* HW semaphore 0*/
#endif
#endif /* DUAL_CORE_BOOT_SYNC_SEQUENCE */

/* USER CODE END PD */

#if defined ( __ICCARM__ ) /*!< IAR Compiler */
#pragma location=0x10040000
ETH_DMADescTypeDef  DMARxDscrTab[ETH_RX_DESC_CNT]; /* Ethernet Rx DMA Descriptors */
#pragma location=0x10040080
ETH_DMADescTypeDef  DMATxDscrTab[ETH_TX_DESC_CNT]; /* Ethernet Tx DMA Descriptors */

#elif defined ( __CC_ARM )  /* MDK ARM Compiler */

__attribute__((at(0x10040000))) ETH_DMADescTypeDef  DMARxDscrTab[ETH_RX_DESC_CNT]; /* Ethernet Rx DMA Descriptors */
__attribute__((at(0x10040080))) ETH_DMADescTypeDef  DMATxDscrTab[ETH_TX_DESC_CNT]; /* Ethernet Tx DMA Descriptors */

#elif defined ( __GNUC__ ) /* GNU Compiler */

ETH_DMADescTypeDef DMARxDscrTab[ETH_RX_DESC_CNT] __attribute__((section(".RxDescripSection"))); /* Ethernet Rx DMA Descriptors */
ETH_DMADescTypeDef DMATxDscrTab[ETH_TX_DESC_CNT] __attribute__((section(".TxDescripSection")));   /* Ethernet Tx DMA Descriptors */
#endif

ETH_TxPacketConfig TxConfig;

ADC_HandleTypeDef hadc1;
ADC_HandleTypeDef hadc3;

ETH_HandleTypeDef heth;

CEC_HandleTypeDef hcec;

RTC_HandleTypeDef hrtc;

SAI_HandleTypeDef hsai_BlockA1;
SAI_HandleTypeDef hsai_BlockB1;

SPDIFRX_HandleTypeDef hspdif1;

SPI_HandleTypeDef hspi5;

TIM_HandleTypeDef htim8;
TIM_HandleTypeDef htim13;

UART_HandleTypeDef huart8;
UART_HandleTypeDef huart1;

PCD_HandleTypeDef hpcd_USB_OTG_HS;

   uint8_t cec_receive_buffer[16];
static void MX_GPIO_Init(void);
static void MX_ADC1_Init(void);
static void MX_ADC3_Init(void);
static void MX_ETH_Init(void);
static void MX_HDMI_CEC_Init(void);
static void MX_RTC_Init(void);
static void MX_SAI1_Init(void);
static void MX_SPDIFRX1_Init(void);
static void MX_SPI5_Init(void);
static void MX_TIM8_Init(void);
static void MX_TIM13_Init(void);
static void MX_UART8_Init(void);
static void MX_USB_OTG_HS_PCD_Init(void);
/**
  * @brief  The application entry point.
  * @retval int
  */
int main(void)
{

/* USER CODE BEGIN Boot_Mode_Sequence_1 */
#if defined(DUAL_CORE_BOOT_SYNC_SEQUENCE)
  /*HW semaphore Clock enable*/
  __HAL_RCC_HSEM_CLK_ENABLE();
  /* Activate HSEM notification for Cortex-M4*/
  HAL_HSEM_ActivateNotification(__HAL_HSEM_SEMID_TO_MASK(HSEM_ID_0));
  /*
  Domain D2 goes to STOP mode (Cortex-M4 in deep-sleep) waiting for Cortex-M7 to
  perform system initialization (system clock config, external memory configuration.. )
  */
  HAL_PWREx_ClearPendingEvent();
  HAL_PWREx_EnterSTOPMode(PWR_MAINREGULATOR_ON, PWR_STOPENTRY_WFE, PWR_D2_DOMAIN);
  /* Clear HSEM flag */
  __HAL_HSEM_CLEAR_FLAG(__HAL_HSEM_SEMID_TO_MASK(HSEM_ID_0));

#endif /* DUAL_CORE_BOOT_SYNC_SEQUENCE */
/* USER CODE END Boot_Mode_Sequence_1 */
  /* MCU Configuration--------------------------------------------------------*/

  /* Reset of all peripherals, Initializes the Flash interface and the Systick. */
  HAL_Init();

  /* Initialize all configured peripherals */
  MX_GPIO_Init();
  MX_ADC1_Init();
  MX_ADC3_Init();
  MX_ETH_Init();
  MX_HDMI_CEC_Init();
  MX_RTC_Init();
  MX_SAI1_Init();
  MX_SPDIFRX1_Init();
  MX_SPI5_Init();
  MX_TIM8_Init();
  MX_TIM13_Init();
  MX_UART8_Init();
  MX_USB_OTG_HS_PCD_Init();
  /* Infinite loop */
  /* USER CODE BEGIN WHILE */
  while (1)
  {
    /* USER CODE END WHILE */

    /* USER CODE BEGIN 3 */
  }
  /* USER CODE END 3 */
}

/**
  * @brief Peripherals Common Clock Configuration
  * @retval None
  */
void PeriphCommonClock_Config(void)
{
  RCC_PeriphCLKInitTypeDef PeriphClkInitStruct = {0};

  /** Initializes the peripherals clock
  */
  PeriphClkInitStruct.PeriphClockSelection = RCC_PERIPHCLK_ADC|RCC_PERIPHCLK_SAI1;
  PeriphClkInitStruct.PLL2.PLL2M = 2;
  PeriphClkInitStruct.PLL2.PLL2N = 12;
  PeriphClkInitStruct.PLL2.PLL2P = 2;
  PeriphClkInitStruct.PLL2.PLL2Q = 2;
  PeriphClkInitStruct.PLL2.PLL2R = 2;
  PeriphClkInitStruct.PLL2.PLL2RGE = RCC_PLL2VCIRANGE_3;
  PeriphClkInitStruct.PLL2.PLL2VCOSEL = RCC_PLL2VCOMEDIUM;
  PeriphClkInitStruct.PLL2.PLL2FRACN = 0;
  PeriphClkInitStruct.Sai1ClockSelection = RCC_SAI1CLKSOURCE_PLL2;
  PeriphClkInitStruct.AdcClockSelection = RCC_ADCCLKSOURCE_PLL2;
  if (HAL_RCCEx_PeriphCLKConfig(&PeriphClkInitStruct) != HAL_OK)
  {
    Error_Handler();
  }
}

/**
  * @brief ADC1 Initialization Function
  * @param None
  * @retval None
  */
static void MX_ADC1_Init(void)
{

  ADC_MultiModeTypeDef multimode = {0};
  ADC_ChannelConfTypeDef sConfig = {0};

  /** Common config
  */
  hadc1.Instance = ADC1;
  hadc1.Init.ClockPrescaler = ADC_CLOCK_ASYNC_DIV1;
  hadc1.Init.Resolution = ADC_RESOLUTION_16B;
  hadc1.Init.ScanConvMode = ADC_SCAN_DISABLE;
  hadc1.Init.EOCSelection = ADC_EOC_SINGLE_CONV;
  hadc1.Init.LowPowerAutoWait = DISABLE;
  hadc1.Init.ContinuousConvMode = DISABLE;
  hadc1.Init.NbrOfConversion = 1;
  hadc1.Init.DiscontinuousConvMode = DISABLE;
  hadc1.Init.ExternalTrigConv = ADC_SOFTWARE_START;
  hadc1.Init.ExternalTrigConvEdge = ADC_EXTERNALTRIGCONVEDGE_NONE;
  hadc1.Init.ConversionDataManagement = ADC_CONVERSIONDATA_DR;
  hadc1.Init.Overrun = ADC_OVR_DATA_PRESERVED;
  hadc1.Init.LeftBitShift = ADC_LEFTBITSHIFT_NONE;
  hadc1.Init.OversamplingMode = DISABLE;
  hadc1.Init.Oversampling.Ratio = 1;
  if (HAL_ADC_Init(&hadc1) != HAL_OK)
  {
    Error_Handler();
  }

  /** Configure the ADC multi-mode
  */
  multimode.Mode = ADC_MODE_INDEPENDENT;
  if (HAL_ADCEx_MultiModeConfigChannel(&hadc1, &multimode) != HAL_OK)
  {
    Error_Handler();
  }

  /** Configure Regular Channel
  */
  sConfig.Channel = ADC_CHANNEL_1;
  sConfig.Rank = ADC_REGULAR_RANK_1;
  sConfig.SamplingTime = ADC_SAMPLETIME_1CYCLE_5;
  sConfig.SingleDiff = ADC_SINGLE_ENDED;
  sConfig.OffsetNumber = ADC_OFFSET_NONE;
  sConfig.Offset = 0;
  sConfig.OffsetSignedSaturation = DISABLE;
  if (HAL_ADC_ConfigChannel(&hadc1, &sConfig) != HAL_OK)
  {
    Error_Handler();
  }
}
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

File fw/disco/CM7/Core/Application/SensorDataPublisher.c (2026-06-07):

//     * **************************************************************** *
//   *                                                                      *
// *          (C) Copyright Matthias Schär, all rights reserved               *
//   *                                                                      *
//     * **************************************************************** *
/// @file SensorDataPublisher.c

/// @brief Implementation of the UART -> TouchGFX sensor-data bridge.
///
/// Also provides the strong override of UartReceiverOnSensor() so the
/// receiver module is wired to the GUI just by linking this file.
#include "SensorDataPublisher.h"

#include "UartReceiver.h"
#include "shared.h"

#include "FreeRTOS.h"
#include "queue.h"

#include <stdbool.h>
#include <stddef.h>

// * ************************************************************************ *
// *                                DEFINES                                   *
// * ************************************************************************ *

/// Queue depth (in samples). Sized for ~half a second of bursty
/// telemetry at the nucleo's publication rate; the GUI consumes the
/// queue once per frame so anything more is wasted RAM.
#define SENSOR_DATA_QUEUE_LENGTH  32U

// * ************************************************************************ *
// *                             STATIC VARIABLES                             *
// * ************************************************************************ *

static QueueHandle_t s_queue;

// * ************************************************************************ *
// *                             GLOBAL FUNCTIONS                             *
// * ************************************************************************ *

bool SensorDataPublisherInit(void) {
  if (s_queue != NULL) {
    return true;
  }
  s_queue = xQueueCreate(SENSOR_DATA_QUEUE_LENGTH, sizeof(sensor_data_t));
  return (s_queue != NULL);
}

void SensorDataPublisherPublish(const sensor_data_t *data) {
  if ((s_queue == NULL) || (data == NULL)) {
    return;
  }
  /* Non-blocking: if the GUI is too slow we drop the sample rather
   * than stall the UART receiver task. */
  (void)xQueueSend(s_queue, data, 0);
}

bool SensorDataPublisherTryReceive(sensor_data_t *out) {
  if ((s_queue == NULL) || (out == NULL)) {
    return false;
  }
  return (xQueueReceive(s_queue, out, 0) == pdTRUE);
}

// * ************************************************************************ *
// *                       UART RECEIVER HOOK OVERRIDE                        *
// * ************************************************************************ *

/// Strong override of the weak hook in UartReceiver.c. Runs in the
/// UART receiver task context.
void UartReceiverOnSensor(const sensor_data_t *data) {
  SensorDataPublisherPublish(data);
}

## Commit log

2026-03-31 [hw] added DSI host for display to CM7 - enabled DSIHOST in video mode - enabled LTDC - moved ownership of SDRAM to CM7 - setup framebuffer on CM7
2026-05-18 [proj] initial setup, added board edge connector for harness adapter
    [t3-harness-adapter.kicad_pcb, t3-harness-adapter.kicad_sch]
2026-05-18 [schematic] added all used connectors
    [t3-harness-adapter.kicad_sch]
2026-05-18 [pcb] component placement
    [t3-harness-adapter.kicad_pcb]
2026-05-18 [pcb] added layout
    [t3-harness-adapter.kicad_pcb]
2026-05-22 [general/structure] moved repo `Disco_TFT_Adapter` into `hw/` directory
    [disco_tft_adapter.kicad_pcb, disco_tft_adapter.kicad_sch]
2026-05-22 [general/structure] moved repo `t3-harness-adapter` into `hw/` directory
    [t3-harness-adapter.kicad_pcb, t3-harness-adapter.kicad_sch]
2026-05-22 [layout] update revision to "Rev. B", rearrange silkscreen and some traces in order to pass DRC without flaws
    [disco_tft_adapter.kicad_pcb]
2026-05-22 [hw/t3-harness-adapter/output] setup output folder structure
    [t3-harness-adapter.kicad_pcb]
2026-05-22 [hw/t3-harness-adapter/schematic] slight adjustment of positioning
    [t3-harness-adapter.kicad_sch]
2026-05-22 [hw/measurement-circuits] initial commit containting rough schematics
    [measurement-circuits.kicad_pcb, measurement-circuits.kicad_sch]
2026-05-22 [hw/measurement-circuits] added formulas to calculate physical values
    [measurement-circuits.kicad_sch]
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2026-05-23 [doc/specification] more explanation about why two STM32 platforms are used
    Additionally: Typos, formatting
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2026-05-23 [fw/nucleo/mx] use UART3 only by M4, add UART1 for M7
    Also, M4 is marked as initializer in CubeMX, so it does not need to
    manually initialize the UART3 anymore.
2026-05-23 [fw/nucleo] implemented IPC
    IPC (inter process communication) from M4 to M7
    FreeRTOS message buffer in shared SRAM4 is used:
    - 0x38000000: `__ipc_mb_struct_start__`
    - 0x38000080: `__ipc_mb_storage_start__`
    For this the cache is disabled.
    HSEM1 is used to send notification from M4 to M7 when a new message
    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
2026-05-23 [fw/nucleo/m7] use agreed UART formatting
    ```
    <id>:<value>;
    ```
    This is how Disco and ESP are expecting the UART frames to arrive.
2026-05-23 [hw/emulator] added
    Simple sensor signal emulator.
    Will be used for testing and for demonstration, as part of the project
    presentation.
    [signal-emulator.kicad_pcb, signal-emulator.kicad_sch]
2026-05-23 [doc/minor] follow same convention for all README files
    Convention is with upper case: `README.md`
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2026-05-29 [fw/nucleo/m4] fix: use unsigned for ADC value
    [conversion.c]
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2026-05-29 [fw/nucleo/m4] lets speed it up to 10 Hz
    Measurement period of all sensors should be 10 Hz acc. to the specification.
2026-05-29 [fw/nucleo/m4] refactoring: dedicated function to handle ring buffer
    Also we need to be able to have more than 255 elements in the ring
    buffer, because for the fuel level we want to have a moving average
    over approx. 30..60 s = 300..600 samples.
2026-05-29 [fw/disco/gitattributes] make sure that the cube MX generated code does not get windoof line endings on linux 🫪
2026-05-29 [fw/disco/project] removed launch and cmake files from the .gitignore so the project doesn't have to be set up on every device
2026-05-29 [fw/nucleo/m4/minor] more precise return type
    Functionally the same, but still, lets use the correct one acc. to
    FreeRTOS API documentation.
    [conversion.c, filtering.c, publication.c]
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2026-05-29 [hw/measurement-circuits] fix: formula for coolant temperature
    [measurement-circuits.kicad_sch]
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2026-05-29 [fw/nucleo/mx] added GPIO inputs for sensors 05..08
    - Sensor 05: Turn signal --> PD0
    - Sensor 06: High beam --> PD1
    - Sensor 07: Oil pressure 0.3 bar --> PD2
    - Sensor 08: Oil pressure 1.8 bar --> PD3
2026-05-29 [fw/nucleo/m4] added binary sensors 05..08
    - Sensor 05: Turn signal
    - Sensor 06: High beam
    - Sensor 07: Oil pressure 0.3 bar
    - Sensor 08: Oil pressure 1.8 bar
    Binary sensor signal: High or low -- simply read via GPIO.
    In the filtering state a debounce is implemented. The M4 keeps reporting
    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
2026-05-29 [fw/nucleo/m4] increased queue size
    We now have more sensors, so lets give a some more buffer size.
2026-05-29 [fw/nucleo/m4] reduced queue timeout
    We don't want to wait for queue slots to be come available, to have
    small measurement time jitter.
    In case the queue is full, we print an error. In this case we would
    need to check on how to improve the system.
2026-06-04 [fw/nucleo/mx] added timer for rotation speed sensor
    We use TIM2:
    - 32 bit timer --> counter period 0xFFFFFFFF
    - Prescale 64-1 --> 1 MHz timer period
    - Channel 1 input capture --> GPIO PA0
    - Interrupt enabled --> Priority 5
    In follow-up commit, ISR can read the timer register and compare it to
    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
2026-06-04 [fw/nucleo/m4] implemented sensor 02: rotation speed
    TIM2 is used to capture the duration between two pulses (resp. two
    rising edges) on GPIO PA0.
    The value is then put into the `queue_data_raw` in unit [pulses per minute].
    The conversion task then converts this value into RPM:
    - 1 RPM generates 4 pulses per minute
2026-06-04 [fw/disco/display] adjusting alignment, color correction, more test rectangles for debugging
    [Display.c, main.c, t3_dash.ioc]
2026-06-04 [fw/esp] implemented first BLE example for water temperature and battery voltage. Used Standard UUID for battery
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2026-06-04 [fw/esp-remotexy] done some changes to fix issues. Code is building and flashing. UI is visible but doesn't change
    [gatt_db.c, uart_task.c]
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2026-06-04 [fw/nucleo/m4] refactoring: added dedicated function to start pulsed sensors
    Currently only one pulsed sensor, but who knows...
2026-06-04 [fw/nucleo/m4] rotation speed: handle timeout
    If we don't receive an input capture for 0.1 s, we assume that the
    motor is not running anymore (too low speed) and we put the value to 0.
    We know that we didn't receive an input capture, if, after 0.1 s we try
    to restart the timer and get a HAL error, indicating that the timer is
    still running. If we would have received a capture in the meantime,
    the time would have been stopped in the ISR.
    [acquisition.c]
2026-06-04 [fw/disco/touchgfx] changed to partial buffer to include a partial display buffer in AXISRAM section (via MDMA). This buffer is needed for large rewrites of the display and prevents glitching effects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
    [main.c, screenView.cpp, t3_dash.ioc]
2026-06-05 [fw/nucleo/m4] sensor rotation speed: fully reset timer if timeout
    Otherwise, some non-zero values will still be reported even if the
    pulse frequency is below the measurement frequency (10 Hz).
    [acquisition.c]
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2026-06-05 [fw/disco/util] set axi interconnect prio to max for SDRAM, avoid sending display buffer when it is written to
    [main.c]
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2026-06-05 [fw/nucleo/m4] sensor rotation speed: increased timeout duration to 1 s
    Otherwise, if we already assume a speed of 0 after 0.1 s, the min.
    measurable speed is 20 pulses per second (as we need two edges for a
    valid measurement), which is 1200 pulses per minute, which is 300 RPM.
    300 RPM is too high, we need to be able to go lower (e.g., 50 RPM).
    Therefore, the timeout duration was increased from 0.1 to 1 s.
    Now we can go down to 30 RPM.
    Btw., the maximum speed is not affected by this. It is only limited
    by int16_t, which is used to represent the speed in pulses per minute,
    i.e., max. speed of 32767 pulses per minute = 8191 RPM.
    [acquisition.c]
2026-06-05 [fw/nucleo/m4] filtering: reduced number of averaging samples for rotation speed
    5 samples is too much for rotation speed. For high RPM values, this
    is 0.5 s, for low RPM values this could go up to 5 s.
    Therefore, it was changed to 2 averaging samples.
    [filtering.c]
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2026-06-06 [fw/disco/init] fixed AXIbus priority setting being overwritten by CubeMX generator
    [main.c]
2026-06-06 [fw/disco/hw] fix USART2 priority, set to 6. Also disable CM4 SPI2 pins. Cannot be used anyways because USART2 now uses the PMOD / STConn + pins
    [main.c, main.h, t3_dash.ioc]
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2026-06-06 [fw/disco/gui] added a "sensor data publisher", takes emitted UART receive signals and puts them in a queue. The screenPresenter then updates the UI with the values received from the queue. Removed t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
2026-06-06 [fw/disco/gui] connect LEDs correctly to the received sensor data
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2026-06-06 [fw/disco/gui] piecewise linear representation of the rpm needle, since the segment 0 ... 1000 rpm is a bit shorter
    [screenView.cpp]
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2026-06-12 [fw/nucleo/conversion] fixed conversion rate from pulses per minute to rpm: one motor revolution = 2 pulses, not 4
    [conversion.c]
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2026-06-13 [fw/nucleo/testing] fixed failing unit test, had to adjust conversion factor
    [conversion_tests.c]
2026-06-15 [fw/nucleo/testing] fixed failing unit test, had to adjust conversion factor (once more)
    [conversion_tests.c]

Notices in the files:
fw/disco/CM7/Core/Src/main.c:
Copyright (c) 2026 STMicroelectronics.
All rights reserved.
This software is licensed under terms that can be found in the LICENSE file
